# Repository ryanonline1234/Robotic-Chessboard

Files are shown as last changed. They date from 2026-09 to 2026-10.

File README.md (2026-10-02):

# Robotic Chessboard

A chessboard that moves its own pieces. An electromagnet on an XY gantry
slides under the board, grabs a piece through the wood, and drags it to its
square, weaving between the other pieces without touching them. It can play
the computer's moves, reset the board after a game, and set up any position.

The hard part of a board like this is the brain: deciding which piece goes
where, in what order, and along which route, so nothing collides. That part
is written and tested. This repo also holds the hardware design, CAD, wiring,
engineering calculations, machine-control software and parts list for the
first physical build.

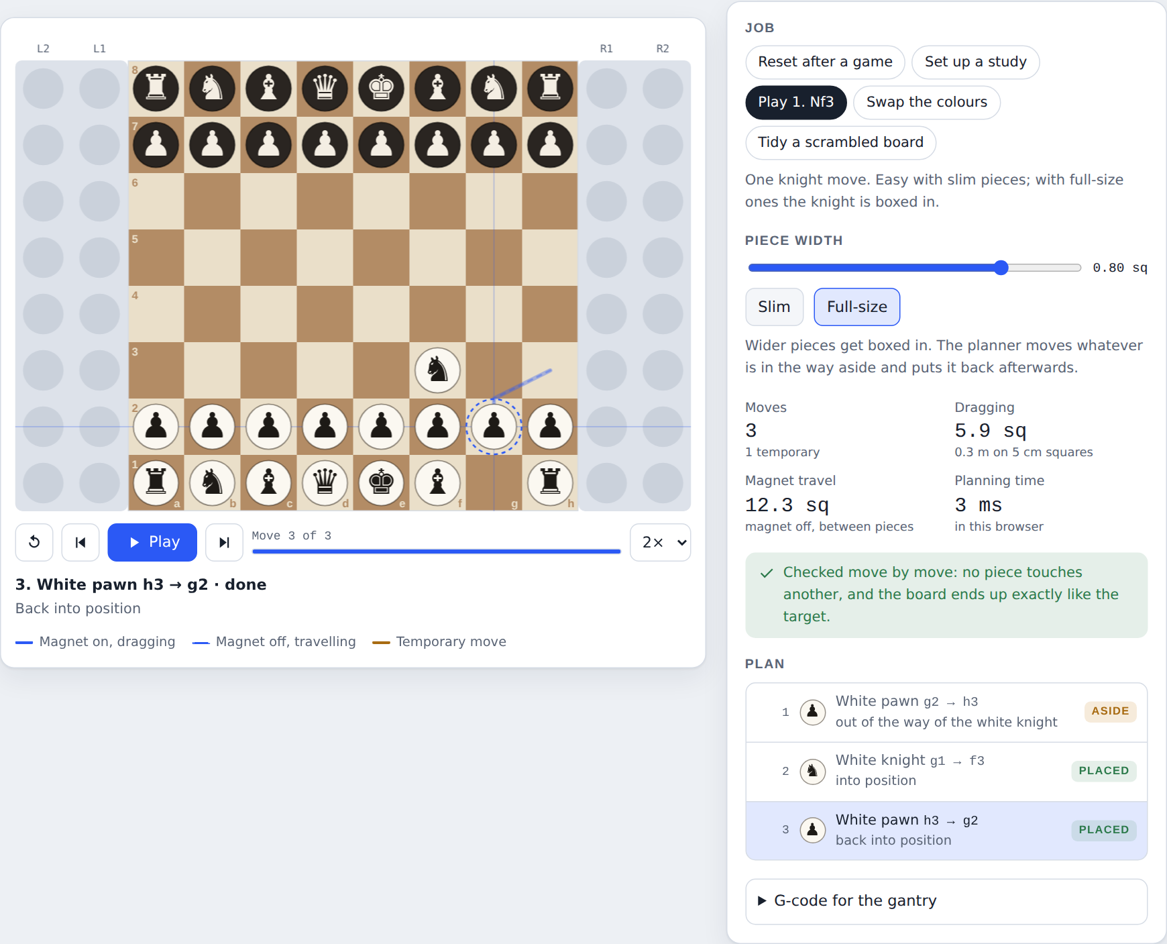
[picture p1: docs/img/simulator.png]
Simulator: a full-size pawn steps aside so the knight can get out, then goes back


## Status

| Part | State |
|---|---|
| Planning software: assignment, collision-free routing, blocker handling | ✅ Done |
| Independent plan checker | ✅ Done |
| G-code output for a GRBL gantry | ✅ Done |
| Animated simulator and command-line demo | ✅ Done |
| G-code sender and board calibration (`send.js`, `calibrate.js`) | ✅ Done, tested against a simulated GRBL |
| Automated tests | ✅ 70, all passing (`npm test`) |
| Hardware design, firmware settings | ✅ [docs/DESIGN.md](docs/DESIGN.md) |
| Engineering calculations | ✅ [docs/CALCULATIONS.md](docs/CALCULATIONS.md) |
| CAD: board sheet, layout drawing, pieces | ✅ [cad/](cad) |
| CAD: gantry, carriage and full assembly, printable STLs | ✅ [cad/README.md](cad/README.md) |
| Wiring schematic | ✅ [docs/img/wiring.svg](docs/img/wiring.svg) |
| Parts list, every price checked on 2026-10-01 | ✅ [docs/BOM.md](docs/BOM.md): $98.36 with tax, under the $100 budget, plus optional add-backs |
| Physical build | Next: [ROADMAP.md](ROADMAP.md) milestones 1–3 |

## What makes it different

- **It plans like a person tidying a board.** Identical pieces are
  interchangeable, so it matches each square with the nearest suitable piece,
  handles pieces that have to swap places, and routes every drag around the
  others with A* search. If a piece is boxed in, it moves the blocker aside and
  puts it back afterwards.
- **It checks its own work.** Every plan is replayed by a separate checker
  with brute-force geometry before a motor turns.
- **It was designed around a measurement, not a guess.** Simulating
  thousands of boards showed that pieces up to half a square wide never block
  each other. With 19 mm bases on 40 mm squares, every piece moves exactly
  once; full-size pieces need up to 2.5 times as many moves.
- **It explains itself.** Every move comes with a reason ("out of the way of
  the white knight") that can be shown on screen.

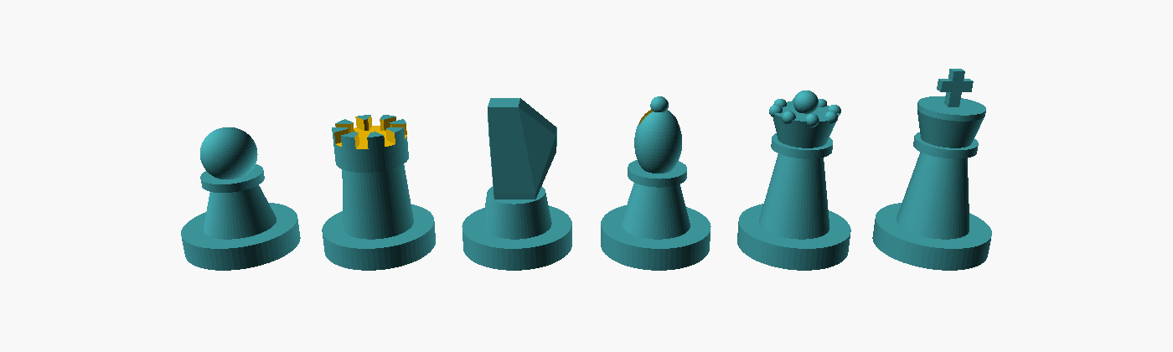
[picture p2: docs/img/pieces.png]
The six 3D-printable piece designs


## Try the software

Needs Node 20 or newer. The planner has no dependencies; `send.js` uses the
optional `serialport` package (`npm install`).

```bash
node demo.js                 # list the sample jobs
node demo.js reset           # put everything back after a game
node demo.js nf3 --big       # full-size pieces: it moves a blocker and puts it back
node demo.js reset --storage 1 --square 40 --size 0.475 --gcode reset.gcode   # G-code for the v1 board
node send.js reset.gcode --dry-run                                            # what would go to GRBL
npm test
```

On the machine, `calibrate.js` fits the G-code to the real board and
`send.js` streams it to GRBL; [docs/DESIGN.md](docs/DESIGN.md#software) has
the steps.

To watch it animated, run `npm run sim` and open
http://localhost:8000/simulator.html.

## How the planner thinks

1. **Assign.** Each target square is matched with a piece of the right type so
   the total distance is as small as possible (Hungarian algorithm, one run per
   piece type). Pieces left over go to storage.
2. **Order.** It runs whichever move has a free destination, nearest to the
   magnet first. When every destination is taken (pieces that must trade
   places), one of them steps onto a spare square first.
3. **Route.** Each drag is found with A* search on a half-square grid, and is
   only allowed if the dragged piece stays one full piece width from every
   other piece the whole way.
4. **Clear the way.** If a piece is boxed in, a second search finds the route
   that disturbs the fewest pieces. They step aside to spots they can get back
   from, then return. With full-size pieces it fills the board from the inside
   out and fills storage from the outer column in.
5. **Check.** `src/verify.js` replays the plan independently.

| Job | Slim pieces (0.45 of a square) | Full-size pieces (0.8) |
|---|---|---|
| Reset after a game | 22 moves | 26 moves (4 temporary) |
| Set up a study | 32 | 32 |
| Play 1. Nf3 | 1 | 3 (1 temporary) |
| Swap the colours | 48 (16 temporary) | 53 (20 temporary) |
| Chess960 setup, average of all 960 | 15.6 (3.6 temporary) | 38.3 (17.1 temporary) |

## Using it from code

```js
import { START_FEN, createBoard } from './src/board.js';
import { planArrangement } from './src/planner.js';
import { toGcode } from './src/gcode.js';

const board = createBoard({ storageColumns: 1 });
const now = { e4: 'P', d5: 'p', 'R1-1': 'Q' /* ...every piece, storage included */ };
const plan = planArrangement(board, now, START_FEN, { pieceDiameter: 0.475 });

for (const move of plan.moves) console.log(move.piece, move.from, move.to, move.why);
const gcode = toGcode(plan.moves, { squareMm: 40 });
```

Inputs can be a FEN string, a `Map` of cell to piece, or an object keyed by
cell name (`e4`, or `L1-3` / `R1-8` for storage slots). The target describes
the 64 play squares; anything not needed there ends up in storage. If a job is
impossible (a second queen that doesn't exist, or more captured pieces than
storage slots), you get `{ ok: false, error }` instead of a plan.

## Repo map

| Path | What it is |
|---|---|
| `src/` | Planner, routing, checker, G-code, sample jobs |
| `src/grbl.js`, `src/send-job.js` | GRBL 1.1 streaming protocol and the send job (errors, alarms, safe stop) |
| `src/calibration.js` | Fits the board to the machine from jogged positions |
| `tests/` | `node --test` suites: planner, G-code, calibration, GRBL streaming against a fake GRBL, CLIs, calculations |
| `demo.js` | Command-line demo; writes G-code |
| `send.js` | Streams a G-code file to GRBL over USB |
| `calibrate.js` | Writes `calibration.json` from the a1 and h8 positions |
| `simulator.html` | Animated top-down simulator |
| `scripts/calculations.js` | Computes every figure in `docs/CALCULATIONS.md` |
| `docs/DESIGN.md` | Hardware design, wiring, firmware settings, test plan |
| `docs/CALCULATIONS.md` | Engineering calculations and what Milestone 1 must measure |
| `docs/BOM.md` | Parts list and budget |
| `docs/img/` | Renders, wiring schematic (`wiring.svg`), screenshots |
| `cad/README.md` | Printed parts, hardware, assembly steps, clearances |
| `cad/params.scad` | Every shared dimension of the gantry |
| `cad/gantry-parts.scad` | The printed gantry parts |
| `cad/assembly.scad` | The whole machine, with fit and reach checks |
| `cad/export.sh` | Rebuilds the STLs and pictures and runs the checks |
| `cad/stl/` | Printable gantry parts |
| `cad/make-wiring.js` | Draws the wiring schematic |
| `cad/board-sheet.svg` | 1:1 printable playing surface (400 × 320 mm) |
| `cad/board-layout.svg` | Same, with dimensions and the magnet's travel area |
| `cad/make-board.js` | Regenerates both drawings for any square size |
| `cad/pieces.scad` | Parametric OpenSCAD pieces with a washer pocket |
| `ROADMAP.md` | Milestones from a magnet test to online play |
| `JOURNAL.md` | Build log |

## License

MIT, see [LICENSE](LICENSE).

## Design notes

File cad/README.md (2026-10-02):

# CAD

Everything needed to print and assemble the v1 gantry, plus the board sheet
and the chess pieces. The OpenSCAD files are parametric: every shared size
lives in `params.scad`.

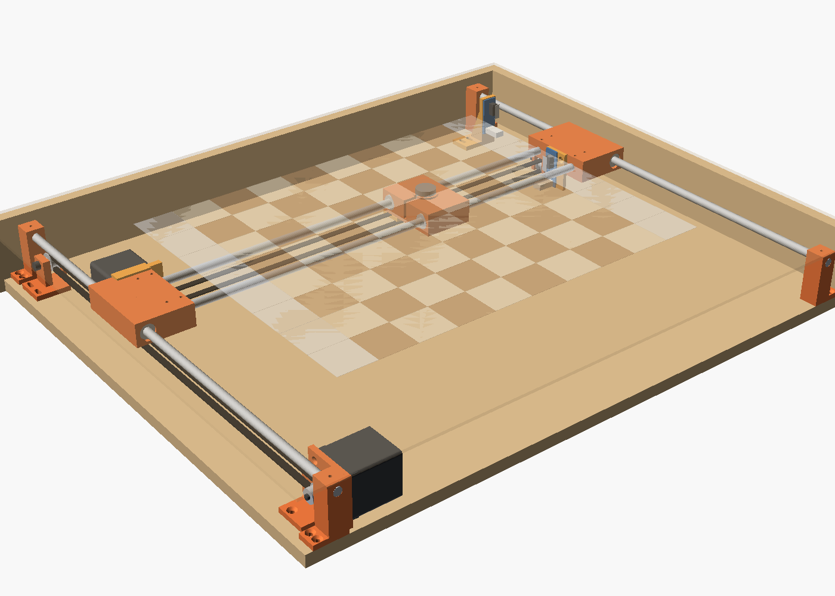
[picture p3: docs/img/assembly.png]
The assembled machine with the top see-through


## Files

| File | What it is |
|---|---|
| `params.scad` | Every shared dimension: grid, rods, bearings, motor, belt, idlers and their axles (`idler_bore`), magnet, clearances, heights, layout, travel limits |
| `gantry-parts.scad` | The ten printed gantry parts, one module each. `part="name"` exports one in its print orientation; `part="all"` lays them all out |
| `assembly.scad` | The whole machine with stand-ins for the bought parts, a section view, a top view, and `echo()` checks for reach, clearances and interference |
| `export.sh` | Writes every STL to `stl/`, renders the four pictures in `docs/img/` and prints the checks. Fails if a check fails. `IDLER_BORE=3` builds the 3 mm idler version ([below](#using-3-mm-idlers)) |
| `stl/` | The exported parts, ready to slice |
| `pieces.scad` | The six chess pieces with a pocket for the steel washer. Its header says to cover the washer with a felt pad; the funded build has no felt (an optional add-back), so the pieces slide on their bare PLA bases |
| `make-board.js` | Draws `board-sheet.svg` (print at 100% and glue on the top) and `board-layout.svg` (the same with dimensions) |
| `make-wiring.js` | Draws the wiring schematic (see its header) |

Regenerate everything with `bash cad/export.sh` (OpenSCAD 2021.01 or newer;
set `OPENSCAD=/path/to/openscad` if it is not on your PATH). On a Linux
machine with no screen, run it as `xvfb-run -a bash cad/export.sh`. It takes
about two and a half minutes, most of it the section picture.

## How it is laid out

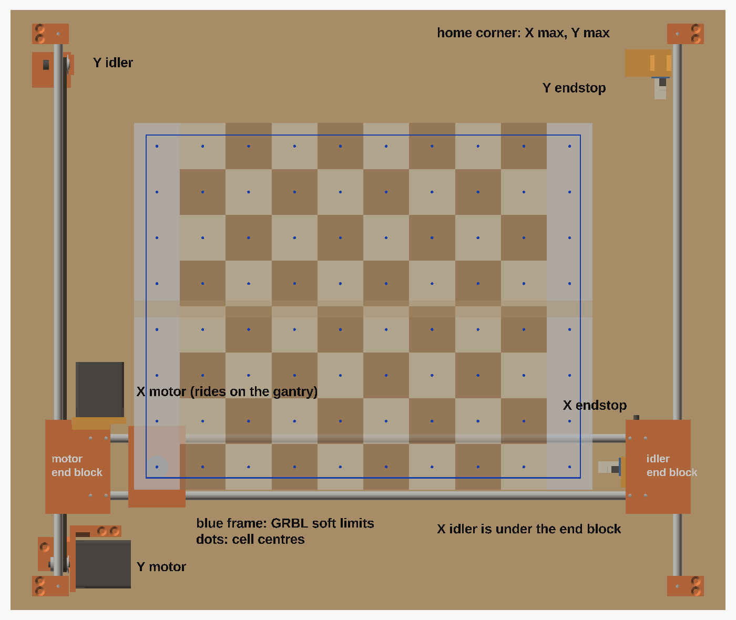
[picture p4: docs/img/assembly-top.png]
Top view, magnet under the front-left storage cell


Machine coordinates start at the front-left corner of the base's top
surface: X to the right (the board's 10 cells), Y away from you (the 8 ranks),
Z up.

- **Y axis.** Two 500 mm rods run front to back on the base at x = 30 and
  x = 570, each held by two printed holders. Each end block rides one rod on two
  LM8UU.
- **X axis.** The two X rods sit 50 mm apart in sockets in the two end
  blocks, at the same height as the Y rods (z = 42.5). Each rod end goes
  25.5 mm into its socket and is locked by two grub screws. The carriage rides
  the rods on four LM8UU.
- **Belts.** Both belts run in vertical loops right under the rods: the X belt
  under the rear X rod, the Y belt under the left end block's bearing housing,
  4.5 mm inboard of the left Y rod. Every pulley and
  idler axle is at z = 24.25, so the upper run of each belt lies flat against
  the underside of the part it pulls (z = 31) and is clamped there. The motors
  lie on their sides.
- **X motor** hangs behind the left ("motor") end block on the X motor mount;
  its pulley sits in a pocket under the end block. A lip along the top of the
  mount rests on the end block, so belt tension can't turn it. The **X idler**
  sits in a slot under the right ("idler") end block.
- **Y motor** is at the front left, **Y idler** at the back left on a mount
  that slides back up to 6 mm to tension the belt. The Y belt pulls the left
  end block, the side that carries the heavy X motor.
- **Switches** are at the back right (X max, Y max), because GRBL homes toward
  + unless `$23` says otherwise. The carriage presses the X switch, which sits
  on a bracket on the idler end block; the idler end block presses the Y
  switch, which sits on a post on the base. Both boards stand on end with the
  switch at the top and the connector at the bottom, below the part that
  presses the lever, so the plug can't stop the switch tripping however tall
  it is.
- **Top.** A frame of four 12 mm plywood walls screwed to the outside edges of
  the base carries the 3 mm top. Nothing touches the top from below except the
  magnet.

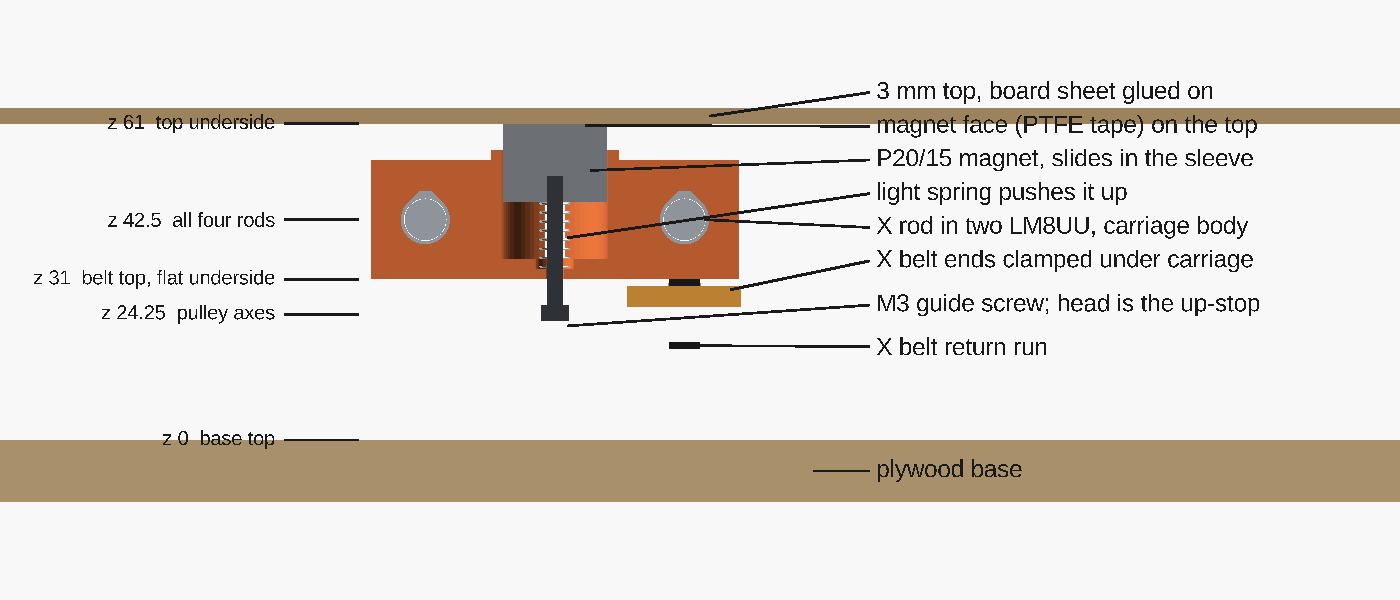
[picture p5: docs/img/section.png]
Section through the magnet: the stack-up


The magnet floats in a sleeve in the carriage. A light spring under it pushes
its face (with PTFE tape on it) up against the underside of the top. An M3
screw comes up through the carriage floor and threads into the magnet's back:
it keeps the magnet upright, and its head stops the magnet 5 mm above the top's
underside when the top is off.

## Printed parts

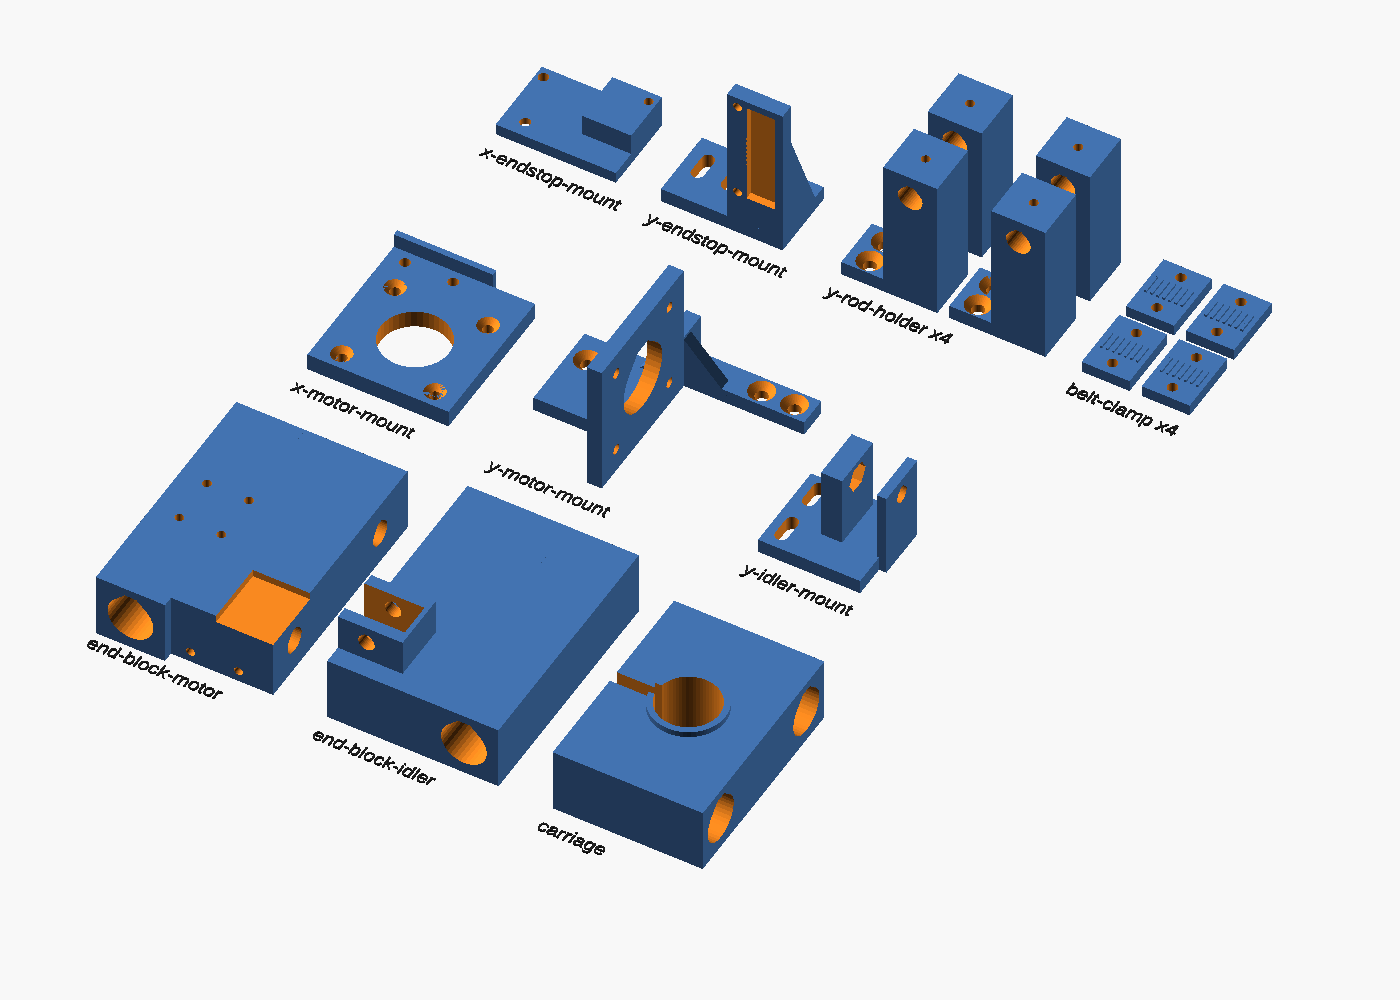
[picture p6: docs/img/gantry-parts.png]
All printed parts in their print orientation


PLA, 0.2 mm layers, 4 perimeters, 30% infill. No supports: horizontal holes
have a 45-degree roof and each part is turned so the only overhangs left are
bridges. The longest is the 9.5 mm roof of the solder-pin pocket in the X
endstop bracket; the rest are 6 mm or less (checked on the STLs). All parts
fit a 220 x 220 mm bed with lots of room.

| Part | Qty | How it sits on the bed | Size on the bed (mm) | Plastic, time (each) |
|---|---|---|---|---|
| `y-rod-holder` | 4 | Standing up, flange down | 32 x 18 x 51 | 12 g, 20 min |
| `end-block-motor` | 1 | Upside down (top face on the bed) | 57 x 82 x 23 | 55 g, 1.5 h |
| `end-block-idler` | 1 | Upside down, idler slot facing up | 57 x 82 x 36 | 58 g, 1.6 h |
| `x-motor-mount` | 1 | Flat, back face down, lip up | 47 x 52 x 11 | 11 g, 19 min |
| `carriage` | 1 | Upright, sleeve up | 50 x 71 x 25 | 41 g, 1.2 h |
| `y-motor-mount` | 1 | Upright, feet down | 73 x 58 x 47 | 16 g, 26 min |
| `y-idler-mount` | 1 | Upright, base down | 36 x 31 x 30 | 9 g, 15 min |
| `belt-clamp` | 4 | Flat, ridges up | 16 x 22 x 5 | 2 g, 3 min |
| `x-endstop-mount` | 1 | Flat, PCB side down | 40 x 27 x 12 | 6 g, 10 min |
| `y-endstop-mount` | 1 | Upright, foot down | 40 x 24 x 55 | 10 g, 17 min |
| **Total** | 16 | | | **about 260 g, 7.3 h** |

Plastic and time are rough estimates from the STL volumes, not from a slicer:
shell = surface area x 1.2 mm, plus 30% of the rest, at 1.24 g/cm³, laid down
at about 8 mm³/s. Your slicer will give better numbers. The chess pieces come
on top of this.

## Hardware

Bought parts from [docs/BOM.md](../docs/BOM.md) that the CAD uses: four 8 x 500
mm rods (uncut), eight of the ten LM8UU (four in the end blocks, four in the
carriage), two NEMA 17 motors, the belt kit's two 20T pulleys and its two 20T
toothed idlers (5 mm bore, on M5 axles), the P20/15 magnet, two mechanical
endstop modules and the PTFE tape for the magnet face. Belt: about 1.0 m for X
and 0.95 m for Y, out of the 5 m roll. Separate 3 mm-bore idlers are an
optional add-back; see [Using 3 mm idlers](#using-3-mm-idlers).

The idlers are drawn 18 mm across the flanges, 8.5 mm wide, 6.5 mm between
the flanges and 12.2 mm across the teeth, from one seller's drawing of a
5 mm-bore 20T idler. Motedis lists a 20T 5 mm-bore idler as 9 mm long, so
the slots take idlers up to 9 mm wide (`idler_w_max`). The nut pocket takes
the thickest nut ISO 4032 allows (4.7 mm for M5). Measure your idlers before
printing the idler end block and the Y idler mount. If one is wider than
9 mm, set `idler_w` and `idler_w_max` (and `idler_gap`) in `params.scad` to
what you measure and run the checks: `bash cad/export.sh`, or
`openscad -o checks.echo cad/assembly.scad` and look for FAIL in
`checks.echo`. If the idler axles check then fails, it names what no longer
fits; change the screw lengths (`x_axle_len`, `y_axle_len`) to suit, and buy
the screws its `SIZE idler axles` line prints.

The X motor must be no longer than 51 mm (the CAD draws a 48 mm body). A
longer one, such as a 60 mm high-torque NEMA 17, hits the back wall before
the Y switch stops the gantry.

The endstop parts are drawn for a 40 x 16 mm board with the switch at one end,
the 3-pin connector at the other, and two holes 35 mm apart, 2.5 mm in from
one long edge. One shop lists the v1.2 board as 36.5 x 16 x 10 mm overall. If
your board's holes are elsewhere, drill new 2.9 mm pilot holes in the bracket
and the post; keep the switch at the top.

Not in the BOM, needed for the build:

| Item | Qty | Where |
|---|---|---|
| M3 x 6 grub screws (set screws) | 12 | Lock the rods: 4 in the holders, 8 in the end blocks (two per X rod end; headless, so nothing sticks up toward the top) |
| M3 x 10 socket screws | 8 | Belt clamps: 4 under the carriage, 4 under the motor end block. Not longer: the pilot holes are 5 mm deep |
| M3 x 10 countersunk (flat head) | 9 | Both motors to their mounts, flush; 1 for the X endstop bracket |
| M3 x 16 socket screws | 2 | X motor mount to the motor end block |
| M3 x 12 socket screws | 2 | X endstop PCB to its bracket |
| M3 x 6 socket screws | 2 | Y endstop PCB to its post |
| M3 x 25 socket screw | 1 | Magnet guide screw |
| M5 x 30 socket screw | 1 | X idler axle: in from the front of the foot under the idler end block, nut on the back face. Its end stands about 4 mm out behind the end block, under it |
| M5 x 20 socket screw | 1 | Y idler axle: in from the outboard side of the Y idler mount, nut in the pocket in the thick cheek. Not longer: a longer screw sticks out into the X motor's path |
| M5 nuts (8 mm across flats, up to 4.7 mm thick: DIN 934 or ISO 4032), M5 washers (10 mm across, 1 mm thick) | 2, 4 | Idler axles (a washer each side of each idler) |
| Wood screws, 3.5-4 mm, about 16 mm long | 19 | 8 for the holders, 3 Y motor mount, 2 Y idler mount and 2 Y endstop post (pan head + washer, in slots), 4 for the top's corners; more for the walls |
| Compression spring | 1 | About 20 mm long, 5-7 mm across, fits over an M3 screw (inside 3.5 mm or more), light: 0.1-0.3 N/mm |
| 12 mm plywood or MDF strips | 2 + 2 | Walls: 624 and 500 mm long, 61 mm plus your base's thickness tall (73 mm for a base of exactly 12 mm) |
| 3 mm hardboard, smooth on both sides (S2S), or 3 mm MDF | 1 | Top, 624 x 524 mm |

The M3 screws in the printed parts cut their own thread in 2.9 mm pilot holes.
The idler axles go through 5.5 mm holes and take nuts. With 3 mm idlers, use
an M3 x 25 and an M3 x 18 socket screw, 2 M3 nuts and 4 M3 washers instead
of the M5 parts (so 2 M3 x 25 in all, with the guide screw). The M3 x 18 goes
in the Y idler mount; not longer, for the same reason as the M5 x 20.

## Assembly

1. **Check the fits.** A rod should slide through the 8.2 mm holes. Press the
   LM8UU into their bores with a vise, two per bore, one from each end until
   they stop against the shoulder in the middle. The magnet should slide
   freely in the sleeve; sand the sleeve if it doesn't. Cut a thread in every
   grub-screw hole by running an M3 socket screw (or an M3 tap) in and out:
   a grub screw on a 1.5 mm hex key can't cut its own thread in PLA.
2. **Carriage.** Put the spring in the pocket on the floor. Push the M3 x 25
   guide screw up through the floor and the spring and screw it into the back
   of the magnet until it bottoms out, then half a turn back. Lead the magnet's
   wires out through the slot. Put two layers of PTFE tape on the magnet face.
   The belt clamp screws come later; their holes pass about 1 mm from the
   bearing bores, so press the bearings in first and don't overtighten them.
3. **Motors.** Fit each pulley before the motor goes on its mount (the pulley
   passes through the 22.6 mm hole):
   - X motor: hub toward the motor, the pulley's end 7 mm from the motor face.
   - Y motor: hub away from the motor, the pulley's end 6 mm from the face.
   Bolt each motor to its mount with four countersunk M3 x 10. Turn the X
   motor so its connector points up or toward the carriage: it runs 3.1 mm
   above the base, and toward the left its plug would hit the Y idler mount.
4. **Gantry.** Slide the carriage onto both X rods. Push the rod ends into the
   two end blocks as far as they go (25.5 mm) and lock each with its two grub
   screws, which end up 1.5 mm below the top of the block. Hang the X motor
   mount on the back of the motor end block with its lip on top of the block,
   and fix it with two M3 x 16 from behind, above the motor. Put the X idler
   with a washer each side in the slot under the idler end block and push the
   M5 x 30 (M3 x 25 for 3 mm idlers) through from the front; the nut goes on
   the back face. Tighten the nut only until the cheeks touch the washers;
   the idler must still spin freely. If it drags, back the nut off, or use
   washers that touch only the bearing's inner ring. Do this before step 8:
   the X endstop bracket sits in front of the screw head.
5. **Y rods.** Stand the gantry on the base. Slide each Y rod in from outside
   through a holder, through the end block's bearings and into the far holder,
   flush with both outer faces, and lock it with the grub screws. Holders go at
   the corners of the base with their flanges outboard (turn the part 180
   degrees for the right side). Screw them down while the gantry slides freely
   end to end; the rods must be 540 mm apart at both ends.
6. **Y drive.** Screw the Y motor mount down at the front left (plate face at
   x = 40, front edge at y = 4); all three of its screws are clear of the Y
   rod. Fit the Y idler in its mount first: drop the nut into the hexagonal
   pocket on the inside of the thick (outboard) cheek, stand a washer, the
   idler and a washer between the cheeks, and screw the M5 x 20 (M3 x 18 for
   3 mm idlers) in from outside through the cheek, the nut, the washers and
   the idler. It ends inside the thin cheek, so nothing sticks out on the
   side the X motor passes. Tighten it snugly: the head and the nut clamp the
   thick cheek. Put the Y idler mount at the back left as far forward as it
   goes, with its axle at x = 34.5, y = 464 and each wood screw at the back end
   of its slot, so the mount can slide back. Drive its two wood screws with a
   screwdriver, or with a bit long enough that its holder stays more than
   25 mm above the mount's base (level with the top of the cheeks): the axle
   head is 1 mm from the bit's path, and a bit holder is wider than the bit.
   Clamp one end of the Y belt under the motor end block, take it forward
   round the Y pulley, back along the bottom, round the idler and forward to
   the second clamp. Pull the belt tight
   through that clamp with pliers and tighten it. Then slide the idler mount
   back (up to 6 mm) to finish tensioning and tighten its screws. Push the
   gantry all the way back by hand: the X motor passes 1.4 mm from the idler
   mount's inner cheek, so check it clears.
7. **X drive.** Same idea: one end under the carriage's left clamp, left round
   the X pulley, along the bottom to the X idler, back to the right clamp.
   Pull the end tight through the right clamp with pliers and tighten it.
   There is no screw tensioner on X: to re-tension later, loosen the right
   clamp from below with a short hex key, pull, and tighten again.
8. **Switches.** Both boards go switch up, connector down.
   - X: screw the bracket to the inner face of the idler end block with the
     countersunk M3 x 10, its block tucked under the end block. Fit the PCB
     with two M3 x 12: the top one goes on through the bracket into the end
     block, the bottom one into the bracket's block.
   - Y: fix the PCB to the post with two M3 x 6. Screw the post down at the
     back right (PCB at x = 547 to 563) and slide it so the switch clicks when
     the X motor is about 5.5 mm from the back wall.
   - Lead each switch cable straight down from its plug to the base, away from
     the carriage, the X belt and the X idler.
9. **Frame and top.** Measure the base's thickness and cut the walls so their
   tops stand 61 mm above the base's top face. Screw them to the outside edges
   of the base. Lay the top on, smooth side down where the magnet slides (with
   one-side-smooth hardboard the sheet will show the texture of the other
   side), and screw or pin it to the walls at the four corners, so it always
   goes back in the same place. Glue the board sheet with its front-left corner
   108 mm from the top's left edge and 105 mm from its front edge, within
   ±5 mm. That centres it in the area GRBL's soft limits allow; the
   calibration in DESIGN.md finds the exact offset.

## Key clearances

| What | Value |
|---|---|
| Rod holes (holders, end blocks) | 8.2 mm, locked with M3 grub screws; X rods 25.5 mm deep in each end block, two grub screws each |
| LM8UU bores | 15.2 mm press fit, 9.5 mm shoulder between the two bearings |
| M3 clearance / self-tapping pilot | 3.4 mm / 2.9 mm |
| Idler axles | 5.5 mm holes for M5 (3.4 mm for M3); slot 11.5 mm for an idler up to 9 mm wide (8.5 mm drawn) and two 1 mm washers (10.5 mm with M3 washers); nut pocket for a nut up to 4.7 mm thick. X: the M5 x 30 ends 5.8 mm past a 4.7 mm nut and 4.3 mm behind the end block's back face, its head 1.3 mm from the X endstop bracket. Y: the M5 x 20 ends 1.4 mm into the 3.3 mm inboard cheek, 1.9 mm short of the face the X motor passes; its head is 1 mm from a 7.3 mm screwdriver bit on the wood screws (so drive them with a screwdriver or a long bit, step 6). At least 1.9 mm of plastic round every axle hole and the nut pocket |
| Belt clamp pilots | 5 mm deep (an M3 x 10 goes in 4.6 mm); about 1 mm of plastic to the bearing bores in the carriage and to the shoulder bore in the motor end block |
| NEMA 17 | 31 mm M3 square, 22.6 mm hole for the 22 mm boss |
| Belts | Pulley and idler axles all at z = 24.25; upper runs at z = 30.4-31.0 on the flat undersides; return runs at z = 17.5-18.9, 3.7 mm below the clamp screw heads |
| Magnet in the sleeve | 20.6 mm bore for the 20 mm magnet |
| Spring | 13 mm long at work, 10 mm if the top sags 3 mm, 18 mm at the up-stop |
| Top | Underside at z = 61. Highest moving parts (sleeve rim, X motor mount lip) at z = 56: 5 mm clear, 2 mm with 3 mm of sag |
| Magnet reach | With `$130=380` and `$131=300` the soft limits allow x 105.9-485.9 and y 103-403. The cell centres are at x 115.9-475.9 and y 113-393: 10 mm to spare on every side (11.5 mm or more to the hard stops) |
| Travel for GRBL | Up to `$130=384` and `$131=309` fit before the far end of travel; DESIGN.md's 380 and 300 stop 4.4 mm (X) and 9 mm (Y) short of it |
| Ends of travel | Parts stop 1 mm apart (end block / Y motor mount, carriage / motor end block); on the home side the switches trip 1.5 mm before the switch body is reached, and the next part is 5.5 mm (Y) or 8 mm (X) away |
| Endstop plugs | Below the face that presses the lever, so any plug height clears; the checks assume a connector and plug up to 18 mm tall |
| Y idler mount | Slides back up to 6 mm; then 1 mm from the back-left holder |
| X motor | 3.1 mm above the base; 1.4 mm from the Y idler mount's inner cheek; at the Y switch's hard stop its back is 4 mm from the back wall (48 mm body) |
| Footprint and height | 624 x 524 mm; 76 mm to the playing surface (with a 12 mm base), 107.5 mm to the top of a king |

## Checks

`assembly.scad` prints these every time it runs (and `export.sh` stops if any
says FAIL):

- the magnet reaches every cell centre with at least 5 mm to spare inside
  GRBL's soft limits (`$130=380`, `$131=300`);
- those soft limits stop short of the hard stops at the far end of travel;
- nothing but the magnet comes within 1 mm of a top that sags 3 mm;
- the spring is never slack or crushed, and the magnet stays in its sleeve;
- the moving parts stay inside the base, so the walls are outside their path;
- each pulley's teeth line up with its belt, and the belts' return runs pass
  under the clamp screws. That the axles all sit at one height and the upper
  runs lie on the flat undersides holds by construction, so it isn't tested;
- at each switch's trip point, measured on the parts' bounding boxes: the
  switch body is still 1.5 mm away, and every other part (the endstop
  connectors and plugs included) is further away than that;
- a bounding-box test finds no overlap between moving and fixed parts at the
  four corners of travel;
- fixed parts that sit close to each other (motor mount and holders, the idler
  mount slid fully back, the Y endstop post) stay at least 1 mm apart;
- the idler axles (M5 or M3, from `idler_bore`), with each nut as thick as
  ISO 4032 allows and each idler as wide as the slots are drawn for, so
  thinner nuts and narrower idlers only leave more room: each hole suits its
  screw, the slots take an idler and two washers, the X axle reaches at least
  1 mm past its nut and its head clears the X endstop, the Y axle reaches
  1 mm or more into the inboard cheek but not out of its face (the X motor
  passes there), the Y axle's head leaves room for a screwdriver on the wood
  screws, and at least 1.5 mm of plastic is left round the holes and the nut
  pocket. The screw heads, the nuts and the X axle's end are also in the
  interference tests. A wrong screw length or nut size in `params.scad` makes
  it say FAIL, for example `-D x_axle_len=20` or `-D axle_nut_h=6`.

The exact interference test renders only the overlaps, at the four corners:

```bash
openscad -D 'check="collide"' -o /tmp/collide.stl cad/assembly.scad
```

OpenSCAD should answer "Current top level object is empty". To see that the
test can fail, push the gantry 6 mm past its front stop with
`-D check_push=6`: it then reports a solid. Each run takes about three
minutes.

Cables are not modelled, so none of these checks cover them.

## Using 3 mm idlers

The funded build uses the belt kit's two 5 mm-bore idlers on M5 axles. Separate
20T idlers with a 3 mm bore, on M3 axles, are an optional add-back. They have
the same outside size, so only two parts change: `end-block-idler` and
`y-idler-mount`. From the repo's top folder, export those two for M3 axles
and run the checks for that build:

```bash
openscad -D idler_bore=3 -D 'part="end-block-idler"' -o end-block-idler-m3.stl cad/gantry-parts.scad
openscad -D idler_bore=3 -D 'part="y-idler-mount"' -o y-idler-mount-m3.stl cad/gantry-parts.scad
openscad -D idler_bore=3 -o checks-m3.echo cad/assembly.scad
```

The two STLs come out in their print orientation, like the ones in `stl/`.
Every CHECK line in `checks-m3.echo` should end in OK, and its
`SIZE idler axles` line lists the M3 screws. The hardware for this option is
under [Hardware](#hardware).

`IDLER_BORE=3 bash cad/export.sh` does the whole export for the 3 mm build
instead: it passes `-D idler_bore=3` to every OpenSCAD run and stops if a
check fails. It overwrites all of `cad/stl/` and the pictures in `docs/img/`,
which in the repo are the 5 mm build; `git checkout cad/stl docs/img` puts
them back. Setting `idler_bore = 3` in `params.scad` switches every command
to the 3 mm build.

## Notes for the firmware and software

- Stock GRBL 1.1 homes Z first and stops with `ALARM:9` on a board with no Z
  switch. Flash it with `HOMING_CYCLE_0` set to X and Y together, as
  [CALCULATIONS.md section 12](../docs/CALCULATIONS.md) describes.
- There are no switches at X min and Y min. If a motor runs the wrong way,
  `$H` drives the carriage or the gantry into the hard stop at the far end and
  keeps going for up to 1.5 x `$130`. Before the first `$H`, jog in small steps
  (`$J=G91 X5 F500`, then `$J=G91 Y5 F500`) and check that +X moves the
  carriage right, toward the idler end block, and +Y moves the gantry back.
  If not, invert that axis with `$3`.
- With the switches at X max / Y max, GRBL's default `$23=0` is right. After
  homing, machine zero is where each switch trips and GRBL counts positions
  downward from there (`limits.c` and `system.c` in GRBL 1.1), so machine
  coordinates on this board run from -`$130` to 0 and the `offsetX` /
  `offsetY` found by jogging to a1 and h8 will be negative too (or set a work
  offset).
- GRBL has one limit input per axis. On the CNC Shield V3 the X- and X+ header
  pins are wired in parallel to that one input (according to builders' forum
  reports, not the maker's documentation), so the switch can plug into X- even
  though it sits at X max.

## Not checked yet

- The spring is not in the BOM, and its rate is a guess. Too stiff and the
  magnet drags on the top; too weak and it may not follow the top's sag.
- The magnet's thread depth, and where its wires leave it, were not measured.
  The slot in the sleeve leaves room either way.
- The endstop board: hole positions follow one datasheet, and the switch
  heights and the connector-and-plug size (18 mm tall) are estimates. A switch
  that trips at a different height only moves machine zero by the difference,
  which the 10 mm margins and the calibration absorb; the Y post can also
  slide to put it back.
- Pulley hub and tooth lengths are typical values, not measured.
- The idlers' size is one seller's drawing, and the belt kit's idlers were
  not seen; measure them. The slots take idlers up to 9 mm wide; see
  [Hardware](#hardware) for a wider one. Whether a 10 mm M5 washer touches
  only the idler's inner bearing ring, as it should, was not checked.
- How much the 600 x 500 mm span of 3 mm hardboard sags is an assumption (3 mm
  allowed). So is the advice about smooth sides: it comes from general
  knowledge of hardboard, not from a sheet measured here.
- The base must be flat to about 1 mm (check with a straightedge; MDF is
  safer than plywood), and nothing may lie on it in the strip the X motor
  sweeps (x 40-90, from y 130 to the back): the motor runs 3.1 mm above it.
- The gantry parts take about 260 g of PLA on top of the pieces, more than the
  BOM's 250 g for everything.
- The electronics are not modelled. Free space under the top: a strip along
  the front (x 95-520, y 0-52) and along the back (x 95-515, y 446-500), both
  61 mm high. Cable routing for the magnet, X motor and switches is not
  modelled either; leave slack loops so nothing reaches the belts.
- The X belt has no screw tensioner; it is tensioned by hand at the carriage
  clamp. GT2 belt stretch over time was not looked up.
- Racking: the Y belt pulls only the left end block (the one with the X
  motor). The right end block is dragged through the X rods, which sit
  25.5 mm deep in both blocks with two grub screws each, and each block runs
  on two LM8UU 79 mm apart end to end. If the rod joints stay rigid, the two
  rods resist racking at about 10.7 N/mm (beam theory, 2 x 12EI/L³ over the
  449 mm between the end blocks; not measured); if a grub screw loosens as the
  PLA creeps, the joint can turn and the right end lags. Whether the gantry stays square is something
  Milestone 2's pen test has to show (draw the right-hand storage column).
- Heat: the magnet sits in a PLA sleeve. PLA softens around 55-60 °C. The
  magnet is only on while dragging, but if it gets too warm to touch during a
  long job, print the carriage in PETG.

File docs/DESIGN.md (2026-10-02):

# Design: compact robotic chessboard (v1)

A chessboard that moves its own pieces. An electromagnet on an XY gantry
slides under the board top, switches on under a piece, drags it along a
route that avoids every other piece, and switches off. The route planning is
done by the software in this repo and sent to the gantry as G-code.

Simulator showing the planner moving a pawn out of the way for a knight

## Specs

| | |
|---|---|
| Square size | 40 mm |
| Grid | 10 × 8 cells: the 8 × 8 board plus one storage column on each side (16 slots for captured pieces) |
| Board surface | 400 × 320 mm, printed sheet on 3 mm hardboard ([cad/board-sheet.svg](../cad/board-sheet.svg)) |
| Magnet travel | 360 × 280 mm between the outermost cell centers ([cad/board-layout.svg](../cad/board-layout.svg)) |
| Machine size | 624 × 524 mm, 76 mm tall to the playing surface ([cad/assembly.scad](../cad/assembly.scad)) |
| Pieces | 3D-printed, 19 mm bases (0.475 of a square), 21–32 mm tall, M8 washer in each base ([cad/pieces.scad](../cad/pieces.scad)); felt pads optional |
| Magnet | 12 V holding electromagnet, 20 mm, switched by a MOSFET from GRBL's `M8`/`M9` |
| Motion | Two NEMA 17 steppers (45 N·cm on Y, a 40 N·cm 17HS4401 on X), GT2 belts, 8 mm rods with LM8UU bearings |
| Controller | Arduino Uno + CNC Shield V3 running GRBL 1.1 |
| Brain | This repo's planner, on a laptop or Raspberry Pi, over USB |
| Power | 12 V 3 A adapter (5 A optional), 5 A fuse |
| Parts | [BOM.md](BOM.md): $98.36 with tax for the funded build, plus optional add-backs |
| Numbers behind the design | [CALCULATIONS.md](CALCULATIONS.md) |

Why 19 mm bases: the planner models each piece as a disc. Pieces up to half a
square wide always fit along the lines between other pieces, so every piece
moves exactly once. Wider pieces get boxed in and need extra moves (the README
has the numbers).

The six piece designs

## Mechanical

The gantry with the board top see-through

The whole machine is modelled in OpenSCAD in [cad/](../cad): every shared
size in [params.scad](../cad/params.scad), the printed parts in
[gantry-parts.scad](../cad/gantry-parts.scad), and the full assembly with its
fit checks in [assembly.scad](../cad/assembly.scad).
[cad/README.md](../cad/README.md) has the parts table, the extra screws,
assembly steps and the key clearances. `bash cad/export.sh` rebuilds the STLs
and pictures and stops if any check fails.

Side section through the magnet carriage

- **Frame:** two Y rods on the base along the left and right edges, held by
  four printed holders. The X gantry is two end blocks joined by the two X
  rods; each end block rides its Y rod on two LM8UU bearings. The magnet
  carriage rides the X rods on four more.
- **Drive:** one stepper per axis with a GT2 belt loop. The Y motor (the
  stronger, 45 N·cm one) sits at the front left and pulls the left end block.
  The X motor rides on that end block, so it must be no longer than 51 mm. The
  X idler sits inside the other end block. The idlers are the belt kit's
  20-tooth idlers with a 5 mm bore on M5 axles; the CAD switches to 3 mm-bore
  idlers on M3 axles with one setting (`IDLER_BORE=3`,
  [cad/README.md](../cad/README.md)). If the gantry racks because only one
  side is driven, move the Y belt toward the middle of the gantry.
- **Constant gap:** the magnet slides in a sleeve in the carriage on an M3
  guide screw, and a light spring pushes it up against the underside of the
  top. Its face is covered in PTFE tape. Magnetic pull falls off quickly with
  distance, so this keeps the grip the same across the whole board, even
  where the top sags.
- **Board top:** a 3 mm sheet on walls around the edge of the base, 5 mm
  above the highest moving part. Nothing supports it from below inside the
  travel area.
- **Homing:** the two endstops sit at the back-right corner (X max, Y max).
  The carriage presses the X switch and the idler (right) end block presses
  the Y switch.
- **Printed parts:** 16 parts, about 260 g of PLA and 7 hours of printing, all
  support-free on a 220 × 220 mm bed: 4 Y rod holders, the motor and idler end
  blocks, the X motor mount, the magnet carriage, the Y motor and Y idler
  mounts, 4 belt clamps, and the X and Y endstop mounts. The STLs are in
  [cad/stl/](../cad/stl).

All printed gantry parts

## Electrical

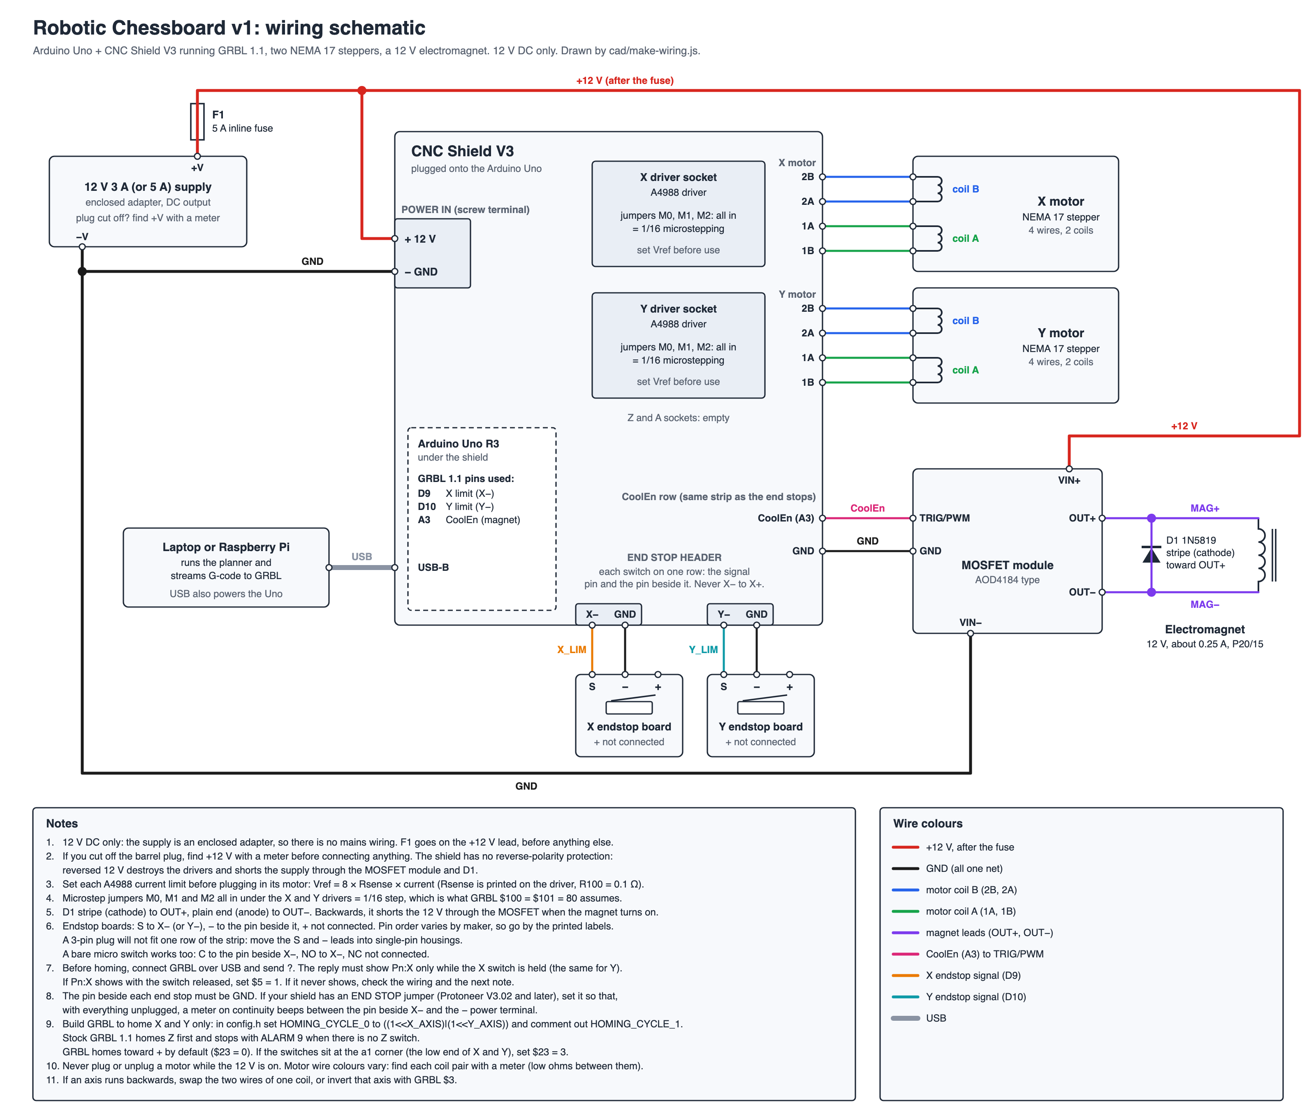
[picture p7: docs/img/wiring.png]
Wiring schematic


Click the picture for the full-size SVG. It is drawn by
[cad/make-wiring.js](../cad/make-wiring.js), and its notes cover current
limits, microstep jumpers, diode orientation and the endstop check.

| From | To | Notes |
|---|---|---|
| Supply +12 V | Fuse, then the shield's power terminal and the MOSFET module's VIN+ | 12 V only, no mains wiring. If you cut off the plug, find +12 V with a meter first: the shield has no reverse-polarity protection |
| Supply −V | Shield GND and the MOSFET module's VIN− | One shared ground |
| Shield X / Y driver sockets | X and Y steppers | Set each A4988's current limit (Vref) before plugging in its motor; all three microstep jumpers in for 1/16 |
| Shield `X-` and `Y-` endstop pins | Endstop boards | S to `X-` (`Y-`), − to the pin beside it, + not connected. Before homing, send `?` and check `Pn:X` shows only while the switch is held |
| Shield `CoolEn` (Arduino A3) and GND | MOSFET module TRIG/PWM and GND | GRBL `M8` turns the magnet on, `M9` off |
| MOSFET module OUT+ / OUT− | Electromagnet | 1N5819 across the magnet terminals, stripe (cathode) to OUT+ |
| Arduino USB | Laptop or Raspberry Pi | Powers the Arduino and carries the G-code |

Power: about 0.87 A from the 12 V 3 A adapter, estimated from the power the
motors, drivers and magnet actually use, so a 3.4× margin. The worst-case
bound, every coil at its full current at once, is 3.22 A, just over 3 A; the
5 A adapter is an optional add-back. Milestones 2 and 3 measure the real draw
([CALCULATIONS.md §11](CALCULATIONS.md#11-power-budget-and-magnet-heat)).

## Firmware settings (GRBL 1.1)

**Flash GRBL with a two-axis homing cycle.** Stock GRBL 1.1 homes Z first,
and this board has no Z switch, so `$H` fails with `ALARM:9`. Before
compiling and uploading GRBL, edit `grbl/config.h`:

```c
#define HOMING_CYCLE_0 ((1<<X_AXIS)|(1<<Y_AXIS))  // home X and Y together
// #define HOMING_CYCLE_1 ((1<<X_AXIS)|(1<<Y_AXIS))
```

Then set these, from [CALCULATIONS.md §12](CALCULATIONS.md#12-recommended-grbl-settings):

| Setting | Value | Meaning |
|---|---|---|
| `$5` | 0 | Limit pins read as triggered when pulled low: suits switches to GND (GRBL's default) |
| `$100`, `$101` | 80 | Steps per mm: GT2 belt, 20-tooth pulley, 1/16 microstepping |
| `$110`, `$111` | 6000 | Maximum speed, mm/min. Y is near the end of its motor's flat torque here, so test Y before raising `$111` |
| `$120`, `$121` | 400 | Acceleration, mm/s²: about 30× below where the king tips, about 3× torque margin |
| `$11` | 0.010 | Junction deviation (GRBL's default) |
| `$20` | 1 | Soft limits after homing |
| `$22` | 1 | Homing on |
| `$23` | 0 | Home toward +X and +Y: the switches are at X max and Y max (GRBL's default) |
| `$25` | 1500 | Homing seek speed, mm/min: homing takes up to 18.7 s, against about 49 s at the default 500 |
| `$130`, `$131` | 380, 300 | Travel limits, mm (the CAD has room for up to 384 and 309) |

Keep the defaults for `$24`, `$26` and `$27`: the slow second approach is what
makes the homed position repeat. After homing, machine coordinates run from
−`$130` to 0 and −`$131` to 0, so the board's offsets come out negative.
Before the first `$H`, jog in small steps and check that +X moves the carriage
toward the idler end block and +Y moves the gantry back; if not, invert that
axis with `$3` ([cad/README.md](../cad/README.md)).

## Software

1. The planner (`src/planner.js`) takes the current arrangement, storage
   included, and a target position, and returns the moves with routes and
   reasons.
2. `src/verify.js` replays the plan and rejects it if any piece would touch
   another.
3. `calibrate.js` fits the board to the machine. Jog the magnet to the
   centers of a1 and h8 (and h1 and a8 for a better fit), then run
   `node calibrate.js --a1 X,Y --h8 X,Y --storage 1 --square 40`. It works out
   the board's offset, the real square size on each axis and any small
   rotation, and writes `calibration.json`. It refuses measurements that look
   like a jog to the wrong square (`--force` overrides).
4. `src/gcode.js` turns the moves into G-code for this board:
   `toGcode(moves, { calibration })`, or `{ squareMm: 40, offsetX, offsetY }`
   without a calibration.
5. `send.js` streams the G-code to GRBL over USB. It waits for each `ok`, and
   leaves the magnet off whenever it stops: after an `error` (it sends `M9`),
   an `ALARM` (GRBL resets itself) or Ctrl-C (feed hold, then reset). It needs
   the optional `serialport` package (`npm install`).

For this board:

```bash
node demo.js reset --storage 1 --size 0.475 --calibration calibration.json --gcode reset.gcode
node send.js reset.gcode --port /dev/ttyUSB0 --home
```

`node send.js reset.gcode --dry-run` prints what would be sent without a
machine attached.

## How it will be tested

These are the "done when" checks from [ROADMAP.md](../ROADMAP.md):

1. **Magnet:** a king follows the magnet 20 cm through the board top ten times
   in a row and stays put when it's off. [CALCULATIONS.md](CALCULATIONS.md#what-milestone-1-should-measure)
   lists what to measure along the way.
2. **Gantry:** after homing, a pen on the carriage hits all 80 cell centers
   within ±1 mm, three runs in a row.
3. **Moves:** the 22-move reset job runs three times with every piece centered
   on its square.
4. **Game:** a full game against Stockfish, then a reset.

## Open questions

- **Grip.** Can the 20 mm magnet drag a king through 3 mm of hardboard plus
  paper? The two estimates in [CALCULATIONS.md](CALCULATIONS.md) straddle the
  pull needed, so this is the biggest risk, and Milestone 1 answers it before
  anything else is built.
- **Pieces the magnet passes.** Drags pass standing pieces 20 mm away with
  the magnet on. The magnet's sideways pull there has to fall to under a
  quarter of its peak, or it drags them along too. Milestone 1 measures it,
  and any fix for weak grip has to be checked against it.
- **Tipping.** On paper the king tips only above about 11500 mm/s² in the
  worst case (no felt, washer flush with the base), 29× the acceleration
  used; Milestone 3 confirms it.
- **Racking.** Is one Y motor enough, or does the gantry rack? Test it in
  Milestone 2.
- **Bought-part sizes.** The endstop board's hole positions, the washers'
  outer diameter and (if you add them) the felt pads' thickness aren't stated
  in their listings; measure them before printing the mounts and pieces.
- **Felt or no felt.** The funded build leaves the felt out. Milestone 1
  tests the pieces both ways; felt is an inexpensive add-back.

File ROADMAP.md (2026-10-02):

# Roadmap: from planner to a real magnet chessboard

The planner in this repo already works. It turns "here is the board now, here
is how it should look" into collision-free drags and G-code. This roadmap
covers the rest: building a board that moves real pieces and plays a game
with you.

It is split into milestones you can finish one at a time, each with a
**done when** test. The first ones are cheap experiments that catch the
problems most likely to sink the project before you have spent much money.
Time estimates assume part-time work (a few hours on a weekend) and leave out
shipping, which can take one to three weeks for parts ordered online.

## How the board works

```
          chess pieces (steel washer in each base, felt pad optional)
  ═══════════════════════════════════════════════════  3 mm board top
                    ┌───────────┐
                    │ electro-  │  rides on the XY carriage, pressed
                    │ magnet    │  lightly against the underside of the top
  ──────────────────┴───────────┴──────────────────  X beam
  Y rails on both sides, two stepper motors and belts

  laptop or Raspberry Pi ──USB──▶ Arduino Uno + CNC Shield (GRBL)
  runs this planner                moves the motors, switches the magnet
```

The planner decides the moves. GRBL firmware on an Arduino drives two stepper
motors to position the magnet, and switching the magnet on and off grabs and
releases pieces.

## Decisions to make first

| Decision | Recommendation | Why |
|---|---|---|
| Square size | 40 mm | Keeps the whole grid at 400 × 320 mm, so short rods and a $100 budget cover it. 50 mm squares are a later upgrade. |
| Storage | One column on each side, 16 slots (`createBoard({ storageColumns: 1 })`) | Enough for the captures in almost every game. The planner refuses a job that needs more room than exists. |
| Pieces | 3D-printed, 19 mm bases ([cad/pieces.scad](cad/pieces.scad)) | At up to half a square wide, pieces slide between the others, so each piece moves once (see the table in the README). |
| What the magnet grabs | An electromagnet on the carriage and a steel washer in each piece, with no magnets in the pieces | A piece with a magnet in it sticks to the electromagnet's iron core even when the power is off, and gets dragged around. |
| Gantry | A simple XY frame on 8 mm rods and LM8UU bearings, one motor per axis | Cheap and easy to build and debug. An aluminium extrusion frame is stiffer and a good later upgrade. |
| Controller | Arduino Uno + CNC Shield V3 running GRBL 1.1, A4988 drivers | Cheap, well documented, and runs the G-code this repo writes. TMC2209 drivers are quieter if the budget allows. |
| Knowing where pieces are | Version 1: no sensors. Version 2: sensors under the squares. | The software can track every move it makes itself. Sensors are a big job, so add them once everything else works. |

The full design is in [docs/DESIGN.md](docs/DESIGN.md) and the parts in
[docs/BOM.md](docs/BOM.md).

## Milestone 0: planner and simulator ✅

Done in this repo:

- [x] Assign pieces to target squares, order the moves, and route every drag around the other pieces
- [x] Move blockers aside and back when full-size pieces are boxed in
- [x] Independent checker that replays each plan
- [x] G-code output for a GRBL gantry
- [x] Animated simulator (`simulator.html`) and command-line demo (`demo.js`)

## Milestone 1: magnet test (1 weekend, about $30)

The riskiest question is whether a magnet under the board can drag a piece
smoothly. Answer it before building anything else.

- [ ] Buy a 12 V electromagnet (20–25 mm across, rated for 2–3 kg of holding force), a logic-level MOSFET module, a flyback diode (1N5819 or 1N4007), a 12 V power supply, M8 steel washers (16 mm across), and a 3 mm sample of your board material (acrylic, MDF or plywood). A few felt pads are optional, to compare.
- [ ] Wire the magnet through the MOSFET, with the diode across the magnet's terminals and its stripe toward +12 V. Without the diode, switching the coil off can destroy the MOSFET.
- [ ] 3D-print three test pieces: a pawn, a knight and a king (the tallest), from [cad/pieces.scad](cad/pieces.scad). Glue a washer into each base and check with a straight edge that it sits flush with the base or just below it. Test them bare first (the funded build has no felt), then with a felt pad on the bottom if you have some.
- [ ] Hold the magnet under the board sample, by hand or on a block, and drag each piece around. Try gaps from 1 to 5 mm and different speeds.
- [ ] Measure what [docs/CALCULATIONS.md](docs/CALCULATIONS.md#what-milestone-1-should-measure) lists: the pieces' friction on the board sheet, the magnet's downward and sideways pull, whether a passing magnet drags a standing pawn, and how hot the magnet gets.

**Done when:** the king follows the magnet across 20 cm ten times in a row
without tipping or getting left behind, and stays put when the magnet is off.

**If it fails:** use a thinner board top, a bigger washer, a stronger magnet or
a heavier, wider base; drag more slowly; keep the top smooth and the pieces on
felt.

## Milestone 2: the gantry moves accurately (2–3 weekends, about $70)

- [x] Design the rod holders, end blocks, magnet carriage and motor, idler and endstop mounts in CAD, and check that the assembly fits and reaches every cell ([cad/](cad))
- [ ] Print the 16 gantry parts ([cad/stl/](cad/stl), about 260 g of PLA)
- [ ] Build the frame: 8 mm rods on a plywood base with LM8UU bearings, following the assembly steps in [cad/README.md](cad/README.md). The carriage has to reach every cell center: a 360 × 280 mm range for 40 mm squares.
- [ ] Mount two NEMA 17 stepper motors with GT2 belts and 20-tooth pulleys, plus a limit switch on each axis for homing.
- [ ] Flash GRBL 1.1 onto the Arduino and set it up:
  - first edit `config.h` so homing runs X and Y only (`HOMING_CYCLE_0`); stock GRBL homes Z first and fails with `ALARM:9` on this board
  - steps per mm, `$100` and `$101`: 80 for GT2 belts on 20-tooth pulleys at 1/16 microstepping, or 40 at 1/8 (check your driver's jumpers)
  - maximum speed, `$110` and `$111`, and acceleration, `$120` and `$121`
  - homing, `$22=1`, `$23=0`, `$25=1500`
  - the full table is in [docs/DESIGN.md](docs/DESIGN.md#firmware-settings-grbl-11)
- [ ] Drive it by hand from a free G-code sender such as Universal Gcode Sender, CNCjs or LaserGRBL.
- [ ] Accuracy test: tape paper over the frame, clip a pen to the carriage, and visit all 80 cell centers.

**Done when:** after homing, the pen hits every square center within ±1 mm,
three runs in a row.

## Milestone 3: first automated moves (1–2 weekends)

- [ ] Mount the electromagnet on the carriage on a light spring, with PTFE tape on its face, so it presses gently against the underside of the board top.
- [ ] Connect the MOSFET input to the CNC Shield's coolant pin (`CoolEn`, Arduino pin A3). `M8` then turns the magnet on and `M9` turns it off, which is what `toGcode` writes.
- [ ] Fix the board top on a frame around the edges, and glue on the printed sheet from [cad/board-sheet.svg](cad/board-sheet.svg) (print at 100% scale).
- [ ] Calibrate: jog the magnet to the centers of a1 and h8 and run `node calibrate.js --a1 X,Y --h8 X,Y --storage 1 --square 40`, which writes `calibration.json`.
- [ ] Set up the pieces the way `node demo.js reset --storage 1` prints its starting board, write the G-code with `node demo.js reset --storage 1 --size 0.475 --calibration calibration.json --gcode reset.gcode`, and run it with `node send.js reset.gcode --port <port> --home`.
- [ ] Tune the drag speed (start at 1000 mm/min), the acceleration, and the pause after switching the magnet.

**Done when:** the 22-move reset job runs three times in a row with every
piece centered on its square at the end.

## Milestone 4: play a game against the computer (2–3 weekends)

No sensors yet. You enter every move on a screen, your own included, and the
robot moves all the pieces. The software always knows where everything is,
because it made every move itself.

- [x] Software: `send.js`, which streams G-code to GRBL over USB. It homes with `$H` first (`--home`), sends one line at a time and waits for `ok`, and stops on `error` or `ALARM` with the magnet off. Tested against a simulated GRBL; not yet run on hardware.
- [ ] Software: save the physical position of every piece, storage included, to a file after each finished move, so a crash or restart doesn't lose track.
- [ ] Software: a game loop using chess.js for the rules and Stockfish for the computer's moves. After each move, plan from the current arrangement to the new position. Captured pieces go to storage automatically.
- [ ] Software: turn `simulator.html` into a controller. Click a piece and a square to make a move, preview the plan, then send it.
- [ ] Keep two spare queens in storage for promotions. The planner refuses any target it doesn't have the pieces for.

**Done when:** you play a full game against Stockfish to checkmate, and then
one click resets the board.

## Milestone 5: detect moves made by hand (3–4 weekends)

- [ ] Put a sensor under each of the 64 squares: reed switches or Hall-effect sensors (for example the A3144), read through eight 74HC165 shift registers or four CD74HC4067 multiplexers by the Arduino, an ESP32 or a Raspberry Pi.
- [ ] These sensors need a small magnet in every piece, which brings back the sticking problem from the decisions table. Before committing, test a fix: put the electromagnet on a small servo lift so it drops away when it's off, use a servo-lifted permanent magnet instead, or change the planner so the magnet travels along the lines between squares when it's off.
- [ ] Software: read the occupancy grid over serial and work out your move with chess.js. A normal move empties one square and fills another, a capture empties two squares before one fills, and castling changes four squares.
- [ ] Software: after every robot move, compare the sensors with the expected position, and retry or warn when a piece didn't land.

**Done when:** you play a whole game by hand without touching the screen, and
the board notices when you knock a piece off its square.

## Milestone 6: online play and polish (ongoing)

- [ ] Play online through the Lichess Board API, which is made for physical boards: stream your game and send your moves with a personal API token.
- [ ] Make it quieter: TMC2209 drivers in StealthChop mode, rubber feet, gentler acceleration.
- [ ] Make it faster: aim for an average robot move under 5 seconds.
- [ ] Build an enclosure with a power switch, a fuse and tidy wiring.
- [ ] Run a reliability soak: random jobs from `src/scenarios.js` overnight, counting misplaced pieces.
- [ ] Planner: a look-ahead search to cut temporary moves when pieces are full size.

## Parts and budget

The funded v1 build comes to $98.36 with tax and shipping, every price
checked on 2026-10-01; the itemised list is in [docs/BOM.md](docs/BOM.md).
Four parts were cut or downgraded to fit the $100 tier (separate 3 mm idlers,
felt pads, a 5 A adapter and a second 45 N·cm motor). They are listed there
as add-backs to buy at build time, with spares for the riskiest parts; the
design works with or without them. Milestone 5 adds roughly $20–40 for sensors, shift
registers and wiring. Quieter TMC2209 drivers and an aluminium extrusion frame
are good upgrades once v1 works.

## Risks to watch

| Risk | Early warning | Fix |
|---|---|---|
| Magnet too weak through the board | Drags stutter in Milestone 1 | Thinner top, bigger washer, stronger magnet, slower drags |
| Pieces follow the magnet when it's off | Pieces creep during travel moves | No magnets in pieces, or lift the magnet away (Milestone 5) |
| The magnet drags pieces it passes | A standing piece next to a drag route shifts | Measure it in Milestone 1; route drags farther from standing pieces, or use a magnet whose pull falls off faster |
| Tall pieces tip over | The king wobbles when a drag starts | Lower acceleration, a heavier or wider base, felt pads |
| Board top sags | Drags work at the edges but not in the middle | The spring-loaded magnet follows the top; otherwise use a stiffer top |
| Squares drift out of line | Pieces land off-center on one side | Square up the frame, then redo homing and calibration |
| Too noisy | Reviews of commercial robotic boards complain about this | TMC2209 drivers, rubber mounts, slower moves |
| Magnet overheats | Too hot to touch after a long job | It's only on while dragging; use PWM to lower its power |

## Safety

- Use low voltage only: 12 or 24 V from an enclosed power supply. Don't wire mains power yourself.
- Put a fuse on the 12 V line and secure every wire so nothing can catch in the belts.
- Always fit the flyback diode across the electromagnet.

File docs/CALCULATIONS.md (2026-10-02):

# Engineering calculations (v1)

The numbers behind the v1 design in [DESIGN.md](DESIGN.md): resolution,
speed, motor torque, the pieces' mass and balance, whether the magnet can
drag them, frame sag, belt length, how long a reset takes, power and heat.

The figures are for the funded build in [BOM.md](BOM.md): no felt under the
pieces, a 12 V 3 A adapter, a generic 17HS4401 motor on X and a STEPPERONLINE
17HS15-1504S-X1 on Y. Where an optional add-back
([BOM.md: Add back when building](BOM.md#add-back-when-building)) changes a
figure, that case is worked too: felt pads in sections 4 to 7, the 5 A
adapter in section 11. The idlers (the belt kit's 5 mm-bore ones, or the
optional 3 mm-bore ones) are 20-tooth either way and change no figure here.

[`scripts/calculations.js`](../scripts/calculations.js) computes and prints
every figure in this document:

```bash
node scripts/calculations.js                          # uses the piece geometry recorded in the script
node scripts/calculations.js --export-stl /tmp/pieces # re-exports the pieces with OpenSCAD and re-measures them
node scripts/calculations.js --stl-dir /tmp/pieces    # re-measures STLs you already exported
```

`npm test` runs the script too ([tests/calculations.test.js](../tests/calculations.test.js))
and checks that the key figures quoted here still match what it prints. Some
of them come from other code: the reset job's time and magnet duty depend on
the planner and on the defaults in `src/gcode.js`. If a change moves one, the
test fails until this document is updated.

Every input is labelled:

- **design**: fixed by the v1 design ([DESIGN.md](DESIGN.md), [BOM.md](BOM.md), [cad/pieces.scad](../cad/pieces.scad), [src/gcode.js](../src/gcode.js))
- **source**: checked against a datasheet, a product listing or GRBL's source code (listed at the end)
- **assumption**: an estimate. The ones that change a conclusion are measured in Milestone 1 (see [What Milestone 1 should measure](#what-milestone-1-should-measure)).

## Results at a glance

| § | Check | Result | Verdict |
|---|---|---|---|
| 1 | Resolution | 80 steps/mm, 0.0125 mm per microstep | Far finer than the ±1 mm target |
| 2 | Top speed | `$110` = 6000 mm/min uses 27% of GRBL's step rate, and 24.5% (X) and 38.5% (Y) of each motor's rule-of-thumb roll-off speed. On Y's published curve the torque holds its peak up to 38.5% of that speed. Counting back-EMF (a rough check), Y's current stays controllable up to about 281 rpm, 1.9× the 150 rpm of 6000 | Comfortable on X. Y is at or a little past the end of its flat torque: fine at 6000, don't raise `$111` without testing |
| 3 | Motor torque | 3.48 N·cm needed on Y, 11.1 N·cm usable from its 45 N·cm motor; 3.25 N·cm needed on X, 9.9 N·cm usable from its 40 N·cm 17HS4401 | 3.2× margin on Y and 3.0× on X at 400 mm/s²; 2.8× and 2.9× at 1000 |
| 4 | Pieces | 3.39–3.73 g each, about half of it the steel washer; centre of gravity 3.6–5.6 mm above the board with no felt (1 mm higher with the optional felt) | Low and stable |
| 6 | Tipping | The worst piece (king) tips at about 13600 mm/s² with no felt (11300 with the optional felt), with no help from the magnet | 34× (28× with felt) above `$120` = 400, not a risk |
| 5, 7 | Grip | A centred pull of about 0.161 N is needed. At the funded build's 3.4 mm gap (no felt) the two estimates are 0.0118 N and 0.200 N, and other points of the same curve give up to 0.268 N. With the optional felt (4.4 mm): 0.0054 N and 0.143 N, up to 0.203 N. None of these is a bound | **Not settled on paper: the biggest risk. Milestone 1 decides it** |
| 7 | Pieces the magnet passes | Drags pass standing pieces 19.9–20 mm away with the magnet on. At μ = 0.3 the sideways pull there must stay below 0.0100 N (what holds a pawn), while the dragged piece needs about 0.040 N | **Not checked on paper. Milestone 1 measures it**, and every fix for weak grip must be re-checked against it |
| 8 | Rod sag | 0.66 mm at the middle of the board, worst case | The magnet's spring takes it up |
| 9 | Belts | 2200 mm of the 5000 mm roll | Plenty |
| 10 | Reset job | 110.8 s (1.8 min); magnet on for 71% of it | The drag feed is the setting that matters |
| 11 | Power | Estimated 0.87 A from the funded build's 3 A adapter (an energy balance). The worst-case bound, 3.22 A, is 0.22 A over 3 A, but reaching it would take 35.6 W in the motors and drivers against 7.4 W estimated | Enough: 3.4× margin on the estimate. Milestones 2 and 3 measure the real draw; the 5 A adapter is an optional add-back |
| 11 | Magnet heat | +19 K after one reset or in a game; +113 K if resets run back to back for half an hour | Fine for play; watch it in long test runs |
| 12 | Homing | Stock GRBL 1.1 homes Z first and stops with an alarm on a board with no Z switch | **Flash GRBL with a two-axis homing cycle** (section 12); homing then takes up to 18.7 s |

## 1. Steps per mm

| Input | Value | Basis |
|---|---|---|
| Belt pitch | 2 mm | design (GT2) |
| Pulley | 20 teeth | design |
| Motor | 200 full steps per turn (1.8°) | source: both motor listings (X: 17HS4401, Y: 17HS15-1504S-X1) |
| Microstepping | 1/16 | design (A4988, all three jumpers fitted) |

The funded build has two different motors. Y moves the whole gantry,
including the X motor, so it gets the stronger one, a STEPPERONLINE
17HS15-1504S-X1 (45 N·cm, 1.5 A). X moves only the magnet carriage and gets a
generic 17HS4401 (40 N·cm, 1.5 A). A second 17HS15-1504S-X1 for X is an
optional add-back. Below, figures tagged "17HS4401 listing" are for the X
motor and come from one seller's listing, not the one the BOM buys from, so
check the listing of the one you buy. Figures tagged "17HS15-1504S-X1
listing" are for the Y motor, from StepperOnline's product page and its
Amazon listing, which agree.

One pulley turn moves the belt 20 teeth × 2 mm = 40 mm.

steps/mm = full steps per turn × microsteps ÷ (teeth × pitch) = 200 × 16 ÷ 40

| Microstepping | Steps/mm | mm per step |
|---|---|---|
| 1/16 | 80 | 0.0125 |
| 1/8 | 40 | 0.0250 |
| full step | 5 | 0.2000 |

**Conclusion:** `$100` = `$101` = 80 with the 1/16 jumpers fitted, or 40 at 1/8.
Step size does not limit accuracy: even a full step (0.2 mm) is five times
finer than the ±1 mm target in Milestone 2. Belt stretch, frame squareness
and calibration will.

## 2. Speed: step rate and `$110` / `$111`

| Input | Value | Basis |
|---|---|---|
| GRBL step-rate ceiling on an Uno | 30000 steps/s per axis | source: GRBL 1.1 README |
| Supply | 12 V | design |
| Motor inductance, X | 2.8 mH per phase | source (17HS4401 listing) |
| Motor inductance, Y | 4.4 mH ±20% per phase (measured at 1 kHz) | source (17HS15-1504S-X1 listing) |
| Motor current | 1.05 A (70% of 1.5 A) | design (DESIGN.md sets Vref to about 70%) |

GRBL keeps a 30000 steps/s limit in its config file but leaves it switched off,
so it will accept faster settings; it just can't produce clean steps beyond that.

max feed = 30000 ÷ steps/mm × 60 = **22500 mm/min at 1/16** (45000 mm/min at 1/8).

So the step rate is not what limits speed. At the chosen `$110` = `$111` = 6000 mm/min:

- 100.0 mm/s = 8000 steps/s, 27% of the ceiling
- 2.50 motor turns per second (150 rpm), 500 full steps/s
- a diagonal rapid (`G0`) runs at 8485 mm/min, because GRBL limits each axis separately

A rule of thumb for the speed where a stepper's torque falls off: the coil
current can still reach full value in one full step up to about V ÷ (2 L I)
full steps per second. At 12 V and 1.05 A:

| Axis | Motor | L | V ÷ (2 L I) | As a feed | 6000 mm/min is |
|---|---|---|---|---|---|
| X | 17HS4401 | 2.8 mH | 2041 full steps/s | 24490 mm/min | 24.5% of it |
| Y | 17HS15-1504S-X1 | 4.4 mH | 1299 full steps/s | 15584 mm/min | 38.5% of it |
| Y, at the listing's +20% | 17HS15-1504S-X1 | 5.28 mH | 1082 full steps/s | 12987 mm/min | 46.2% of it |

The Y motor has more holding torque than X's (45 N·cm against 40) but more
inductance, so its torque starts to fall at a lower speed. The one published
pull-out curve found is for this motor: StepperOnline's, measured at 24 V and
1.5 A with 2000 microsteps per turn and a driver it doesn't name. It reads
42–43 N·cm from 30 to 210 rpm, then 40 N·cm at 300 rpm, 25 at 600 and 10 at
1200. The rule of thumb at the curve's own settings,
24 ÷ (2 × 4.4 mH × 1.5 A), gives 545 rpm, where the curve reads 28 N·cm, 65%
of its peak. The peak holds up to 210 rpm, 38.5% of that speed, and 93% of
it is left at 300 rpm, 55%. So on this motor the rule of thumb marks the
speed where about a third of the torque is already gone, not where the fall
begins.

`$111` = 6000 runs the Y motor at 38.5% of its own rule-of-thumb speed, the
same fraction as the end of the flat part of the curve: it should still have
about its low-speed torque, with little room to go faster before the torque
falls. X, at 24.5%, has more room. This comparison is rough. It assumes the
curve's shape scales with V ÷ (L I), which is the rule of thumb's own
assumption. It takes the curve's 1.5 A as the peak current; the curve
doesn't say, and read as an rms value the flat part would reach a higher
fraction, so on that question this is the cautious reading. No curve was
found for the 17HS4401.

The rule of thumb also leaves out back-EMF, the voltage the turning motor
generates in its own coils. Back-EMF is set by speed, not current, so it
takes twice the share of 12 V that it takes of 24 V, and on that count
scaling the 24 V curve down to 12 V is optimistic. A rough check that
includes it treats each phase as a sine-driven motor. Its torque constant
k_t is one phase's torque per amp on section 3's convention, holding torque
÷ (√2 × 1.5 A): 0.19 N·m/A on X and 0.21 on Y, an estimate. Its back-EMF at a rotor
speed ω (rad/s) is k_t ω (in SI units the torque constant and the back-EMF
constant are the same number), so a coil needs √((R I + k_t ω)² + (50 ω L I)²)
volts, where 50
is the number of electrical cycles per turn (200 full steps ÷ 4): the
back-EMF is in phase with the current and the inductive drop is 90° ahead of
it. The A4988's two transistors and sense resistor take 1.05 A × (2 × 0.43 +
0.1 Ω) = 1.01 V, which leaves 11.0 V:

| Axis | Needs at 150 rpm (6000 mm/min) | Current controllable up to | Multiple of 150 rpm |
|---|---|---|---|
| X, 17HS4401 | 5.1 V | about 388 rpm | 2.6× |
| Y, 17HS15-1504S-X1 | 6.8 V | about 281 rpm | 1.9× |
| Y, at the listing's +20% inductance | 7.2 V | about 256 rpm | 1.7× |

The same check at the curve's own 24 V and 1.5 A gives about 535 rpm (with
no driver drops, since the curve doesn't name its driver; that raises the
figure and makes what follows a little cautious). The curve's peak holds to
39% of that. `$111` = 6000 is 53% of Y's 281 rpm, and if the curve's shape
scales with this limit instead of V ÷ (L I), the curve at 53% of 535 rpm
(286 rpm) reads 40.5 N·cm, 94% of its peak. So counting back-EMF, Y at 6000
is a little past the end of the flat part rather than at it: still fine, with
less room to go faster than the rule of thumb suggests.

The default drag feed in `src/gcode.js`, `F2000`, is 33.3 mm/s or 2667 steps/s.

**Conclusion:** keep `$110` = `$111` = 6000. Section 10 shows that 10000
would only save 5 s on a whole reset, because most travel moves are short
and spend their time speeding up and slowing down. Y is the axis to test
first if `$111` is ever raised: it is already at or a little past the end of
the flat part of its torque curve, and the back-EMF check puts the speed
where its current can no longer keep up at about 1.9 times 6000.

## 3. Moving masses and motor torque

| Input | Value | Basis |
|---|---|---|
| 8 × 500 mm steel rod | 197.3 g | calculated: 7.85 g/cm³ (assumption) × π/4 × 8² × 500 mm |
| LM8UU bearing | 15 g | assumption (listings say 15–16 g) |
| Bearings on the carriage | 4 | assumption (two per X rod) |
| Printed carriage | 40 g | assumption |
| Electromagnet | 25 g | assumption (Adafruit's 5 V P20/15 is listed at 22.7 g) |
| Spring, screws, belt clamps on the carriage | 15 g | assumption |
| X motor (17HS4401) | 350 g | assumption (40 mm NEMA 17 bodies are often listed near 280 g; this allows a heavier one) |
| Printed end blocks and mounts | 80 g | assumption |
| Pulley, idler, screws on the gantry | 20 g | assumption |
| Resistance per axis | 5 N | assumption: binding from imperfect rod alignment, belt bending, the magnet's PTFE face sliding on the top |
| Holding torque | X: 40 N·cm; Y: 45 N·cm | source (17HS4401 listing; 17HS15-1504S-X1 listing) |
| Current factor | 1.05 A ÷ (√2 × 1.5 A) = 0.49 | assumption: the holding torque is rated with both phases at 1.5 A (the usual convention; neither listing says) |
| Speed derating | 0.5 | assumption: half of that torque is left at speed with microstepping |
| Rotor inertia | 54 g·cm² | source on X (17HS4401 listing). Not found for Y, so assumed the same (see below the table) |

- **Carriage** (moves in X): 4 × 15 g bearings + 40 g printed + 25 g magnet + 15 g hardware = **140 g**
- **Gantry** (moves in Y): 2 rods 395 g + 4 bearings 60 g + X motor 350 g + printed 80 g + hardware 20 g + carriage 140 g = **1045 g**
- **Piece**: at most 4.82 g (section 4). The magnet drags it, not the belts; its share of the load is negligible.

Belt force F = m a + resistance. Motor torque T = F r + J a ÷ r, where r is
the pulley's pitch radius, 20 × 2 mm ÷ 2π = 6.37 mm, and J the rotor inertia.

**Usable torque.** The A4988's current limit (1.05 A) is the peak of the sine
wave it drives through each coil when microstepping. At every microstep the
torque is then about what one phase gives at 1.05 A. If the X motor's
40 N·cm holding torque is rated with both phases at the full 1.5 A, one phase
at 1.5 A gives 40 ÷ √2 N·cm, so at 1.05 A the motor gives
40 × 1.05 ÷ (√2 × 1.5) = 40 × 0.49. Half of that is left at speed: usable
torque = 40 × 0.49 × 0.5 = 9.9 N·cm on X, and 45 × 0.49 × 0.5 = 11.1 N·cm on Y.

The Y motor's published curve (section 2) reads 43 N·cm at low speed at
1.5 A, where this model gives 45 ÷ √2 = 32 N·cm at 1.5 A before the speed
derating. So the model looks cautious if the curve's 1.5 A is the peak
current. Read as rms (2.12 A peak), the model gives 45 N·cm there, close to
the curve's 43, and the two agree with no hidden margin. The curve doesn't
name its driver or say which it means, so it is not used in place of the
model.

| Axis | Acceleration mm/s² | m a (N) | Resistance (N) | Belt force (N) | Torque (N·cm) | Usable (N·cm) | Margin |
|---|---|---|---|---|---|---|---|
| X | 400 | 0.06 | 5.0 | 5.06 | 3.25 | 9.9 | 3.0× |
| Y | 400 | 0.42 | 5.0 | 5.42 | 3.48 | 11.1 | 3.2× |
| X | 1000 | 0.14 | 5.0 | 5.14 | 3.36 | 9.9 | 2.9× |
| Y | 1000 | 1.04 | 5.0 | 6.04 | 3.93 | 11.1 | 2.8× |

The rotor's own inertia adds only 0.034 N·cm at 400 mm/s². The Y motor's
rotor inertia was not found: neither its product page nor its Amazon listing
gives it, and StepperOnline's full datasheet, a download from the product
page, was not opened. The table uses the 17HS4401's 54 g·cm² for it. Even at
twice that, Y would need 3.52 N·cm instead of 3.48.

**Conclusion:** the motors have about three times the torque needed: 3.2× on
Y and 3.0× on X at 400 mm/s². Y carries the heavier load, and its stronger
motor gives it the larger margin. The assumed 5 N of friction and binding is
most of the load, and the moving mass hardly matters. If an axis stalls or
skips, look for binding (rods out of parallel, a tight bearing) before
blaming the motor.

## 4. Piece mass and centre of gravity

**Method.** Each piece in [cad/pieces.scad](../cad/pieces.scad) was exported
as an STL (`$fn` = 64, OpenSCAD 2021.01). The script reads the triangles and
sums signed tetrahedra to get each piece's volume and the centre of that
volume, and sums the triangle areas to get the surface area and its centre.
The measured values are recorded in the script; `--stl-dir` or
`--export-stl` measures them again.

| Input | Value | Basis |
|---|---|---|
| PLA density | 1.24 g/cm³ | assumption (typical figure) |
| Infill | 20% | assumption (pieces.scad suggests 15–20%) |
| Solid walls | 0.8 mm | assumption: 2 perimeters of 0.4 mm, 4 top and bottom layers of 0.2 mm |
| M8 washer | 16 mm × 8.4 mm × 1.6 mm, steel 7.85 g/cm³ | design; density assumption |
| Washer position | glued against the top of the 1.8 mm pocket, so its face is 0.2 mm up inside it | assumption: glue between the washer and the top of the pocket makes the 0.2 mm smaller |
| Felt pad (optional add-back; the funded build has none) | 1.0 mm thick | assumption |

- **Printed mass** = 1.24 g/cm³ × (walls + 20% of the inside), where walls = surface area × 0.8 mm (at most the whole volume). A solid print (100%) is the upper bound.
- **Washer**: π/4 × (16² − 8.4²) × 1.6 = 233.0 mm³ of steel = **1.83 g**, its face 0.2 mm up inside the pocket and its centre 1.0 mm above the bottom of the base.
- **Centre of gravity** (CG) = (m_body × z_body + m_washer × z_washer) ÷ (m_body + m_washer), measured from the bottom of the base. In the funded build the base stands on the board, so that is the height above the board; the optional felt adds 1.0 mm to every height. The body's CG combines the walls (at the centre of the surface area) and the infill (at the centre of the volume).

| Piece | Height (mm) | Volume (cm³) | Area (cm²) | Printed (g) | Solid (g) | With washer (g) | CG (mm) | CG if solid (mm) | CG off-axis (mm) |
|---|---|---|---|---|---|---|---|---|---|
| pawn | 21.5 | 1.82 | 14.0 | 1.56 | 2.25 | 3.39 | 3.6 | 4.7 | 0.00 |
| rook | 22.0 | 2.41 | 16.4 | 1.90 | 2.99 | 3.73 | 4.9 | 6.2 | 0.00 |
| knight | 26.0 | 2.10 | 15.2 | 1.73 | 2.60 | 3.56 | 4.6 | 5.9 | 0.15 |
| bishop | 27.0 | 1.88 | 15.3 | 1.68 | 2.33 | 3.51 | 4.4 | 5.0 | 0.01 |
| queen | 28.0 | 2.30 | 16.5 | 1.88 | 2.85 | 3.71 | 5.4 | 6.6 | 0.00 |
| king | 31.5 | 2.34 | 16.6 | 1.90 | 2.90 | 3.73 | 5.6 | 6.8 | 0.00 |

"With washer" uses the 20% print; "CG off-axis" uses the solid print. The CG
columns are for the funded build; add 1.0 mm with the optional felt.

**Conclusion:** every piece weighs 3.39–3.73 g, and the 1.83 g washer is about
half of it, so the CG sits low: 5.6 mm above the board for the 31.5 mm king
(6.8 mm if printed solid; 6.6 and 7.8 mm with the optional felt), a quarter
of its height or less. The knight's head moves its CG only 0.15 mm off the
axis. The 34-piece set (32 plus two spare queens) needs about 58 g of PLA at
20% infill, before skirts and purges: the "about 60 g" the BOM allows for
the pieces, out of about 320 g of PLA on hand. The felt pad's own mass is
ignored.

## 5. Magnet pull through the board (estimate)

Every grip and tipping figure depends on how hard the magnet pulls the washer
through the board top. No force-versus-gap curve was found for the P20/15,
so this is the weakest estimate in the document.

**The gap** between the magnet face and the washer:

| Layer | Funded build (mm) | With the optional felt (mm) | Basis |
|---|---|---|---|
| PTFE tape on the magnet | 0.1 | 0.1 | assumption |
| Board top | 3.0 | 3.0 | design |
| Printed paper sheet and glue | 0.1 | 0.1 | assumption |
| Felt pad | none | 1.0 | design (the funded build has no felt); thickness an assumption |
| Washer recess in the pocket | 0.2 | 0.2 | assumption: the washer glued against the top of the 1.8 mm pocket (1.6 mm washer); glue there makes it smaller |
| **Total** | **3.4** | **4.4** | |

**The reference curve.** The closest published curve found is for the Eclipse
Magnetics M52180/12VDC, a 12 V holding magnet of similar size and power to
the P20/15, rated for 100% duty:

| | Eclipse M52180/12VDC | P20/15 (the BOM magnet) |
|---|---|---|
| Size | 20 mm across, 18 mm long | 20 mm across, 15 mm long |
| Mass | 36 g | 22.7 g (Adafruit's 5 V version) |
| Power | 2.5 W (12 V, 210 mA) | 3 W (12 V, 0.25 A) |
| Rated pull in contact | 53 N | 2.5–3 kg (24.5–29 N) in listings, about half the Eclipse's |

Its datasheet gives 53 N in contact, 22 N at 0.09 mm, 9 N at 0.18 mm, 5 N at
0.27 mm, 3 N at 0.36 mm, 2 N at 0.59 mm and 1 N at 1.00 mm (±10%), measured
on its M52171/25ARM armature plate, 25 mm across and 3 mm thick. The table
gives whole newtons only, so the last two points, 2 N and 1 N, fix the slope
only roughly. The pull has already dropped to 2% of its contact rating at
1 mm, and the table stops there.

Two ways to carry it on to 3.4 and 4.4 mm:

- **High estimate**: continue the slope between the last two points: F = 1 N × (1 mm ÷ gap)^1.31.
- **Low estimate**: scale down to the P20/15's lower rating (24.5 N, from listings that say 2.5 kg; some say 3 kg) and assume the pull falls with the cube of the gap beyond 1 mm: F = 1 N × 24.5/53 × (1 mm ÷ gap)³. (Assumption: once the gap is larger than the spacing between the magnet's poles, more of the flux goes straight from pole to pole without crossing the steel, so the pull falls faster than near contact.)

| Gap | High estimate (N) | Low estimate (N) | Heaviest piece's weight (N) |
|---|---|---|---|
| 3.4 mm (funded build, no felt) | 0.200 | 0.0118 | 0.047 |
| 4.4 mm (with the optional felt) | 0.143 | 0.0054 | 0.047 |
| 2.4 mm (no felt, 2 mm top) | 0.317 | 0.0334 | 0.047 |

The high estimate depends on which table points set the slope. The same
power law through the 1.00 mm point, starting from each earlier point:

| From | Exponent | Pull at 3.4 mm (N) | Pull at 4.4 mm (N) |
|---|---|---|---|
| 0.09 mm (22 N) | 1.28 | 0.208 | 0.149 |
| 0.18 mm (9 N) | 1.28 | 0.208 | 0.150 |
| 0.27 mm (5 N) | 1.23 | 0.222 | 0.162 |
| 0.36 mm (3 N) | 1.08 | 0.268 | 0.203 |
| 0.59 mm (2 N), the high estimate | 1.31 | 0.200 | 0.143 |

Neither estimate allows for the washer being smaller than the test plate, or
for the 8.4 mm hole in its middle. Adafruit gives the P20/15 a "center
diameter" of 8 mm, which on a pot-shaped holding magnet like this is the
centre pole, so the hole sits right over it. Both make the real pull lower;
by how much was not worked out.

**Conclusion:** through the funded build's 3.4 mm the two extrapolations
give 0.0118 N and 0.200 N, 0.25 and 4.23 times the weight of the heaviest
piece, and other points of the same table give 0.200 to 0.268 N. With the
optional felt (4.4 mm) they give 0.0054 N and 0.143 N, 0.11 and 3.02 times
that weight, and 0.143 to 0.203 N from other points. None of these is a
bound: the washer's shape can make the real pull lower than all of them, and
the table's coarse whole-newton points leave the high end uncertain. Leaving
out the 1 mm felt pad, as the funded build does, multiplies the pull by 1.40
on the high estimate and 2.17 on the low one. A 2 mm top would multiply the
funded build's pull by another 1.58 (high) or 2.84 (low).

## 6. Tipping

When the magnet speeds a piece up or slows it down, the piece's inertia acts
at its CG (height h) while the magnet drives it low down, at the washer
(height z_w). The piece would tip about the edge it stands on (radius r): the
edge of its printed base in the funded build, or of the felt pad with the
optional felt. Taking moments about that edge at the moment the far side
lifts, for the braking case (the worse one, because friction then adds to the
tipping moment):

m a (h − z_w) = (m g + F_v) (r − μ z_w)

**a_tip = (g + F_v ÷ m) × (r − μ z_w) ÷ (h − z_w)**

where F_v is the magnet's downward pull and μ the friction coefficient of
the base (or the felt) on the sheet. Speeding up gives r + μ z_w instead,
which is more stable. Ignoring the magnet's pull and putting the drive at the
board surface gives the simple bound **a_tip = g r ÷ h**, which is lower than
the full formula whenever r > μ h. That holds for every piece here, in both
cases, so the simple bound is the safe figure.

| Input | Funded build (no felt) | With the optional felt | Basis |
|---|---|---|---|
| r, less the CG's off-axis offset | 9.5 mm, the edge of the 19 mm base | 9.0 mm, an 18 mm felt pad cut a little inside the base | design ([cad/pieces.scad](../cad/pieces.scad)); the felt's size is an assumption |
| z_w | 1.0 mm | 2.0 mm | washer centre (section 4), plus the felt |
| μ | 0.3 | 0.3 | assumption (section 7) |
| F_v, 0.5 × the centred pull at that gap | 0.0059 N (low estimate) or 0.100 N (high) | 0.0027 N (low) or 0.071 N (high) | assumption (section 7) |
| h, m | solid prints from section 4 | the same, h 1 mm higher | the heavier, higher-CG case |

- A: g r ÷ h, no magnet pull, drive at the board surface
- B: g (r − μ z_w) ÷ (h − z_w), drive at the washer while braking, no magnet pull
- C: the full formula with the magnet's pull, low and high estimates

Funded build, no felt:

| Piece | CG (mm) | Mass (g) | A (mm/s²) | B (mm/s²) | C low (mm/s²) | C high (mm/s²) | A ÷ `$120` |
|---|---|---|---|---|---|---|---|
| pawn | 4.7 | 4.08 | 19900 | 24500 | 28100 | 85700 | 50× |
| rook | 6.2 | 4.82 | 15100 | 17500 | 19700 | 54500 | 38× |
| knight | 5.9 | 4.43 | 15600 | 18200 | 20700 | 60200 | 39× |
| bishop | 5.0 | 4.16 | 18500 | 22400 | 25600 | 77500 | 46× |
| queen | 6.6 | 4.68 | 14100 | 16100 | 18100 | 51200 | 35× |
| king | 6.8 | 4.73 | 13600 | 15500 | 17400 | 48900 | 34× |

With the optional felt:

| Piece | CG (mm) | Mass (g) | A (mm/s²) | B (mm/s²) | C low (mm/s²) | C high (mm/s²) | A ÷ `$120` |
|---|---|---|---|---|---|---|---|
| pawn | 5.7 | 4.08 | 15500 | 22400 | 23900 | 62200 | 39× |
| rook | 7.2 | 4.82 | 12300 | 16000 | 16900 | 40100 | 31× |
| knight | 6.9 | 4.43 | 12600 | 16600 | 17600 | 43900 | 32× |
| bishop | 6.0 | 4.16 | 14600 | 20500 | 21800 | 56300 | 37× |
| queen | 7.6 | 4.68 | 11600 | 14700 | 15600 | 37500 | 29× |
| king | 7.8 | 4.73 | 11300 | 14100 | 15000 | 35900 | 28× |

(Rounded to the nearest 100 mm/s².)

**With no felt the washer is exposed.** The washer pocket is open at the
bottom of the base, 16.4 mm across in the 19 mm base
([cad/pieces.scad](../cad/pieces.scad)), so a piece with no felt stands on a
1.3 mm ring of PLA, with the washer's face 0.2 mm above the board (section
4). If the washer sits flush with that ring or stands proud of it, as glue
between the washer and the top of its pocket or a washer as thick as the
1.8 mm pocket would make it, the piece stands on the steel instead. Its
friction on the sheet changes (no figure for steel on paper was looked for),
it tips about the washer's edge (r = 8.0 mm), and the washer may mark the
printed sheet. Tipping is still no risk: A for the king becomes 11500 mm/s²,
29× `$120`. Milestone 1 checks where the washers sit
([What Milestone 1 should measure](#what-milestone-1-should-measure)).

**Conclusion:** even with no help from the magnet, the king only tips above
about 13600 mm/s² in the funded build, 34 times the 400 mm/s² that `$120` /
`$121` allow. With the optional felt it is 11300 mm/s², 28 times: the pad is
narrower than the base and lifts the CG by 1 mm. Either way the washer keeps
the CG low enough that GRBL's acceleration cannot tip a piece. If a king
wobbles in testing, look elsewhere first: the base (or the felt) catching on
a seam or the edge of the sheet, a piece being dragged into another one, or a
piece that falls behind the magnet and is yanked when it catches up.

## 7. Grip: does the piece follow the magnet?

While the magnet drags a piece, the piece trails behind it until the sideways
pull matches the resistance. The base (or the felt, if added) resists with μ
times the total downward force, which is the piece's weight **plus the
magnet's own downward pull**, so a stronger magnet adds friction as well as
grip:

- needed sideways force = μ (m g + F_v) + m a
- available sideways force = s F_v

where s is the ratio of sideways to downward pull at the trailing offset
where the sideways pull is largest. The piece keeps up if

**F_v (s − μ) ≥ μ m g + m a**

If s is no bigger than μ, no magnet is strong enough.

| Input | Value | Basis |
|---|---|---|
| Piece | rook, solid print: 4.82 g, weight 0.0473 N | section 4 (the heaviest) |
| m a | 0.0019 N at 400 mm/s² | |
| μ, the piece on the paper sheet | 0.3 (0.2–0.4 tried) | assumption: no published figure found for bare printed PLA on paper (the funded build) or for felt on paper (the optional add-back), so the same value and range stand for both |
| s | 0.5 (0.4–0.7 tried) | assumption: no source found |
| F_v at that offset | 0.5 × the centred pull | assumption |

The m a term is small next to friction (μ m g = 0.0142 N), so a lower
acceleration barely helps grip.

**The funded build has no felt.** That is lever 2 at the end of this
section, already taken, and it changes three things:

- **The gap** is 3.4 mm instead of 4.4, so the magnet pulls 1.40 (high estimate) to 2.17 (low) times as hard, on the dragged piece and on the pieces it passes alike (section 5).
- **The friction coefficient** is that of the printed base on the sheet, not felt. Neither was found, so both keep μ = 0.3 with 0.2–0.4 tried. Milestone 1 measures bare PLA first, then felt.
- **Standing pieces** feel the stronger pull too. What holds one in place is μ m g with the base's μ (plus friction from the magnet's downward pull on it, which only helps and is ignored below), while the sideways pull on it grows with the magnet's strength. "Pieces the magnet passes" below works out what that asks of the magnet.

The next two tables don't depend on the felt; the comparison after them
covers both gaps.

Centred pull needed (N), for each μ and s:

| μ | s = 0.4 | s = 0.5 | s = 0.7 |
|---|---|---|---|
| 0.2 | 0.114 | 0.076 | 0.046 |
| 0.3 | 0.322 | 0.161 | 0.081 |
| 0.4 | never | 0.417 | 0.139 |

The largest gap that still gives that pull, for s = 0.5, on the two curves
from section 5:

| μ | Pull needed (N) | High-estimate gap (mm) | Low-estimate gap (mm) |
|---|---|---|---|
| 0.2 | 0.076 | 7.1 | 1.8 |
| 0.3 | 0.161 | 4.0 | 1.4 |
| 0.4 | 0.417 | 1.9 | 1.0 |

With μ = 0.3 and s = 0.5, the 0.161 N needed compares with:

| Gap | Pull | ÷ pull needed | Sideways force needed (N) | Available (N) | Ratio |
|---|---|---|---|---|---|
| 3.4 mm, funded build | High estimate, 0.200 N | 1.24 | 0.0462 | 0.0501 | 1.08 |
| 3.4 mm, funded build | Top of the range from other table points, 0.268 N | 1.66 | 0.0564 | 0.0671 | 1.19 |
| 3.4 mm, funded build | Low estimate, 0.0118 N | 0.07 | 0.0179 | 0.0029 | 0.16 |
| 4.4 mm, with felt | High estimate, 0.143 N | 0.89 | 0.0375 | 0.0357 | 0.95 |
| 4.4 mm, with felt | Top of the range from other table points, 0.203 N | 1.26 | 0.0466 | 0.0508 | 1.09 |
| 4.4 mm, with felt | Low estimate, 0.0054 N | 0.03 | 0.0169 | 0.0014 | 0.08 |

Adding the felt back costs 1 mm of gap, so it only helps grip if the felt
slides enough more easily than bare PLA to make up for the weaker pull. With
bare PLA at μ = 0.3, felt breaks even at μ = 0.26 on the high estimate's
slope and 0.20 on the low one's; a felt with a higher μ than that makes grip
worse.

**Pieces the magnet passes.** A switched-on magnet pulls on every washer near
it, not only the one it is dragging. [src/motion.js](../src/motion.js) keeps
at least one piece diameter, 19 mm (0.475 × 40 mm), between a dragged
piece's centre and every other piece's centre. In the 22-move reset job,
drags pass a standing piece within 20 mm 22 times; the closest is 19.9 mm.
A washer 20 mm off the magnet's axis has its near edge 12 mm from the axis,
just outside the magnet's 10 mm radius. A standing piece slides towards the
magnet once the sideways pull on it is more than μ (m g + F_v there). The
lightest piece is a pawn at 20% infill (3.39 g). The table compares the
sideways pull the dragged piece needs (s × F_v at the centred pull needed,
s = 0.5) with what holds a standing pawn, ignoring the magnet's downward
pull on the pawn, which only helps it stay put:

| μ | Centred pull needed (N) | Peak sideways pull needed on the dragged piece (N) | What holds a standing pawn, μ m g (N) | Ratio of the two |
|---|---|---|---|---|
| 0.2 | 0.076 | 0.0190 | 0.0067 | 2.9× |
| 0.3 | 0.161 | 0.0403 | 0.0100 | 4.0× |
| 0.4 | 0.417 | 0.1043 | 0.0133 | 7.8× |

So the design needs a pull that is strong right over the piece and weak
20 mm out. At μ = 0.3, with a magnet just strong enough to drag the rook,
the sideways pull 20 mm from the axis must be under a quarter of its peak
over the dragged piece. A stronger magnet needs the pull to fall off even
faster, because what holds a standing pawn stays the same. That is the
funded build's case if the high end of section 5 holds: at the 3.4 mm gap,
the peak sideways pull (s × 0.5 × the centred pull) is 5.0 times what holds
a standing pawn at the high estimate (0.200 N) and 6.7 times at the top of
the range (0.268 N), so the pull 20 mm out must fall below a fifth, or a
6.7th, of its peak. With the felt the same figures are 3.6 and 5.1 times.
Leaving the felt out strengthens the pull on the pieces the magnet passes
along with the one it drags. No force-versus-offset data were found to check
this. Milestone 1 measures it (step 4).

**Conclusion:** on paper the grip is unsettled. In the funded build (3.4 mm,
no felt) the high estimate of the pull is a little more than what is needed:
1.24 times it from the last two table points, up to 1.66 times from other
points of the same table, which gives 1.08 to 1.19 times the sideways force
needed. The low estimate gives less than a fifth of that force. With the
optional felt (4.4 mm) the high estimate is about equal to what is needed
(0.89 to 1.26 times) and the low one gives less than a tenth. This is the
"riskiest question" the roadmap puts first, and these numbers cannot settle
it: the answer swings across the whole range with μ, s and the real pull,
none of which could be checked. Milestone 1 measures them. If they land at
the weak end, these are the levers (the first two are sized in the tables
above; the last two were not quantified):

1. Less friction under the piece, which raises s − μ: going from μ = 0.3 to 0.2 halves the pull needed (0.161 N to 0.076 N). A smoother sheet, or a pad that slides better than bare PLA; felt (the optional add-back) helps only if its μ is low enough to pay for the 1 mm it adds to the gap (see above).
2. A smaller gap. The funded build already leaves out the 1 mm felt, which multiplies the pull by 1.40 to 2.17 over the felt version (section 5). A 2 mm top would multiply it by another 1.58 to 2.84.
3. A plain steel disc without a hole instead of the M8 washer.
4. A stronger magnet.

Each lever also changes how hard the magnet pulls on the pieces it passes,
so re-check every one against that limit. Levers 2, 3 and 4 strengthen the
pull 20 mm out as well as over the dragged piece. Lever 1 lowers what holds a
standing pawn (0.0100 N to 0.0067 N), but it lowers the grip needed more, so
the ratio needed falls from 4.0× to 2.9×.

Acceleration and drag speed hardly enter this model (friction is assumed not
to depend on speed), so slowing down is not a fix by itself.

One more effect to measure: when the magnet stops, the piece stops where the
sideways pull falls to the static friction, some distance short of the
magnet's centre. If that distance is more than about 1 mm, the G-code could
overshoot each drag slightly and come back. That would be a software change
and is not done here.

## 8. Rod deflection

| Input | Value | Basis |
|---|---|---|
| Rod | 8 mm, I = π d⁴ ÷ 64 = 201.1 mm⁴ | design |
| Steel modulus E | 200000 N/mm² | assumption |
| Span | 500 mm, simply supported | assumption: the whole rod length, which overstates the sag |
| Magnet spring preload | 2 N | assumption: the top end of a "light" spring |

The spring pushes the magnet up against the board top and pushes the
carriage down by the same amount, so the X rods carry the carriage's weight
plus the preload. The magnet's pull on a piece does not load the rods: the
magnet is already pressed against the top, and the top takes that force. The
Y rods carry the whole gantry plus the preload. Each pair of rods shares its
load equally, and the worst case puts all of it at mid-span.

- point load at mid-span: δ = P L³ ÷ (48 E I)
- the rod's own weight: δ = 5 w L⁴ ÷ (384 E I) = 0.078 mm

| Rods | Load per rod | Sag from the load | With own weight |
|---|---|---|---|
| X (carriage 1.37 N + spring 2 N, ÷ 2) | 1.69 N | 0.109 mm | 0.19 mm |
| Y (gantry 10.25 N + spring 2 N, ÷ 2) | 6.12 N | 0.397 mm | 0.47 mm |

**Conclusion:** at the middle of the board the carriage sits at most 0.66 mm
lower than at the corners. The spring keeps the magnet pressed on the top, so
this does not change the gap. Rod holders that clamp the ends rigidly would
cut the sag from the loads to a quarter (P L³ ÷ (192 E I): 0.027 mm on X,
0.099 mm on Y), though printed holders are not fully rigid. Give the spring at least 3 mm
of working travel; that figure is a judgment, not a calculation, to cover the
frame's flatness and any sag of the board top as well.

## 9. Belt lengths

Each axis has one belt loop: from the moving part, around the motor pulley,
back along the axis, around an idler, and back to the moving part, with both
ends clamped.

loop = 2 × centre distance + 20 teeth × 2 mm (half of each pulley) + 2 × clamp allowance

| Input | Value | Basis |
|---|---|---|
| Centre distance, pulley to idler | 500 mm | assumption: about one rod length (the CAD sets the real figure) |
| Clamp allowance | 30 mm per belt end | assumption |
| Roll | 5000 mm | design (BOM) |

One loop = 2 × 500 + 40 + 2 × 30 = **1100 mm**. X and Y together use 2200 mm,
leaving 2800 mm. If the gantry racks and needs a second Y belt, a third loop
still leaves 1700 mm. The idlers are 20-tooth either way, the belt kit's
5 mm-bore ones in the funded build or the optional 3 mm-bore ones, so the
loop is the same with both.

## 10. Reset job: time and magnet duty

**Method.** The script plans the reset job exactly as
`node demo.js reset --storage 1 --square 40 --size 0.475` does, writes its
G-code with `src/gcode.js`, and runs that G-code through a model of GRBL 1.1's
motion planner:

- `G0` at `$110`/`$111` and `G1` at the programmed feed, each axis limited separately, as GRBL does
- speeds ramp at `$120`/`$121`; corners slow down by GRBL's junction-deviation rule with `$11` = 0.010 mm, and straight runs of segments keep full speed
- `M8`, `M9` and `G4` wait for motion to stop (GRBL empties its buffer for them), so every drag starts and ends at rest
- the magnet starts and ends at `X0 Y0`, the outer corner of the left storage column (offsets of 0)

Not modelled: homing (up to 18.7 s, section 12), delays in streaming
G-code over USB (the sender is assumed to keep GRBL's buffer full), and
GRBL's stepwise speed updates.

The planner's figures: 22 moves, 2397 mm dragged, 2101 mm of empty travel
between moves. The G-code adds the trips out from and back to `X0 Y0`, so it
has 2352 mm of `G0` travel and 2397 mm of `G1` drags.

With `$110` = 6000, `$120` = 400 and `F2000`:

- travel 27.8 s + drags 74.2 s + pauses 8.8 s = **110.8 s (1.8 min)**
- magnet on for 78.6 s, **71%** of the job, 3.57 s per move
- drags average 32.3 mm/s against the 33.3 mm/s set by `F2000`; corners slow them down

| Settings | Travel (s) | Drags (s) | Pauses (s) | Total (s) | Magnet on |
|---|---|---|---|---|---|
| recommended | 27.8 | 74.2 | 8.8 | 110.8 | 71% |
| drag `F1000` | 27.8 | 144.8 | 8.8 | 181.3 | 82% |
| drag `F3000` | 27.8 | 51.7 | 8.8 | 88.3 | 64% |
| `$120` = 800 | 24.9 | 73.0 | 8.8 | 106.6 | 73% |
| `$110` = 10000 | 22.6 | 74.2 | 8.8 | 105.6 | 74% |

**Conclusion:** a reset takes just under two minutes, plus homing. Dragging
is 74.2 s of the 110.8 s, so the drag feed is the only setting that changes
the total much: `F3000` would take 88.3 s, and `F1000`, where Milestone 3 starts
tuning, 181.3 s. Doubling the acceleration saves 4 s and `$110` = 10000
saves 5 s, which is not worth the extra noise. Use the fastest drag feed that
passes the Milestone 3 test.
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

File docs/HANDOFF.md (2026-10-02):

# Handoff: after the design push

The warm-up submission closes **Sunday, October 4 at 11:59 PM**.

## Where things stand (2026-10-01)

The design push is done. The saved workflow
([`.claude/workflows/robotic-chessboard-design-push.js`](../.claude/workflows/robotic-chessboard-design-push.js))
ran all five tracks, each with an independent review and a fix pass:

| Track | Result |
|---|---|
| Gantry and assembly CAD | [cad/](../cad): 16 printed parts, STLs, assembly with fit and reach checks, four renders. `bash cad/export.sh` passes all its checks |
| Wiring schematic | [img/wiring.svg](img/wiring.svg), drawn by `cad/make-wiring.js` |
| Engineering calculations | [CALCULATIONS.md](CALCULATIONS.md), every figure printed by `scripts/calculations.js` |
| G-code sender and calibration | `send.js`, `calibrate.js`, `src/grbl.js`, `src/send-job.js`, `src/calibration.js` |
| Parts list | [BOM.md](BOM.md): every row checked on 2026-10-01 |

The full-spec parts list came to $116.38, so four parts were cut to fit the
$100 tier: the separate 3 mm idlers (the belt kit's 5 mm idlers are used,
and the CAD's idler bore is now a setting), the felt pads, the 5 A adapter
(3 A instead) and the second 45 N·cm motor (a 17HS4401 on X instead). **The
funded list is $98.36 with tax.** The cut parts, plus spares and other
improvements, are in [BOM.md: Add back when building](BOM.md#add-back-when-building),
to be bought separately at build time.

## Open before ordering

1. **Prices that can move** ([BOM.md](BOM.md#prices-that-can-change)): the
   X motor (row 3) and the bearings (row 6) are on sale until Oct 7; the
   fuse holders (row 12) are on sale with no end date shown.
2. **Quantities.** Rows 10 and 13 buy more than one of an AliExpress item;
   the regular price for a second unit wasn't tried in a cart.
3. **Belt kit idlers.** Row 5's two idlers come from the kit's description.
   If they don't arrive, buy the 3 mm idler pack (an add-back) and print the
   two idler parts for 3 mm ([cad/README.md](../cad/README.md#using-3-mm-idlers)).

## Notes

- AliExpress blocks automated visits to its product pages, but its search
  results load. Prices were read from the search page's quick-view panel with
  the variant selected. After many quick-views it starts showing a CAPTCHA.
- The washers must be plain carbon steel. Stainless washers are barely
  magnetic.
- Sales tax in San Jose is 10.000% since 2026-04-01 (Measure A).

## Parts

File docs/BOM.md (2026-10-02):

# Parts list (funded build)

Everything needed for the compact v1 board in [DESIGN.md](DESIGN.md): an XY
gantry that moves an electromagnet under a 400 × 320 mm board top. This is
the list submitted for the $100 tier 3 funding. Four parts were cut or
downgraded to fit the budget; they, and other parts that would improve the
board, are listed under [Add back when building](#add-back-when-building),
to be bought separately at build time. The design works either way.

Prices are in US dollars for a US buyer, and every row was checked on
2026-10-01. Amazon and eBay rows were checked on the product page itself.
AliExpress blocks automated visits to its product pages, so AliExpress rows
were checked in the quick-view panel of its search results, with the exact
variant selected. Each price is the regular price anyone pays; AliExpress's
$1.09 "new shoppers" deals are left out. Three rows are sales that anyone gets
right now (rows 3, 6 and 12); see [Prices that can change](#prices-that-can-change).

**Total: $98.36, which is $1.64 under the $100 tier 3 budget.**

| # | Part | What it's for | Qty | Unit $ | Line $ | Vendor | Link |
|---|---|---|---|---|---|---|---|
| 1 | Arduino Uno R3 + CNC Shield V3 + 4 × A4988 drivers with heatsinks, USB cable (kit) | Uno runs GRBL 1.1; the shield drives both motors, switches the magnet from CoolEn (A3) and reads the X−/Y− endstops | 1 | 7.88 | 7.88 | AliExpress (Realpoy Module Wholesale Store) | https://www.aliexpress.us/item/3256806291794239.html |
| 2 | STEPPERONLINE NEMA 17 stepper, 45 N·cm, 1.5 A, 39 mm body, 1 m cable | Y axis motor (moves the whole gantry); also lifts the Amazon order over $35 so it ships free | 1 | 12.99 | 12.99 | Amazon (sold by StepperOnline) | https://www.amazon.com/dp/B07LF898KN |
| 3 | NEMA 17 stepper 17HS4401, 1.5 A, 40 mm body, with Dupont cable | X axis motor (moves only the magnet carriage) | 1 | 5.25 | 5.25 | AliExpress (JINGLIN 3D Store) | https://www.aliexpress.us/item/3256808478690312.html |
| 4 | Linear rods, 8 mm × 500 mm, case-hardened chrome, pack of 4 | Two Y rods on the base, two X rods on the gantry | 1 | 23.99 | 23.99 | Amazon (sold by Sharp Domain Hardware, ships from Amazon) | https://www.amazon.com/dp/B0C2MJMMQM |
| 5 | GT2 6 mm belt 5 m + 2 × 20T pulleys (5 mm bore) + 2 × 20T idlers (5 mm bore) (kit) | Belts, motor pulleys and the two belt idlers | 1 | 7.67 | 7.67 | AliExpress (KUFAN 3D Printer Store) | https://www.aliexpress.us/item/3256809943699118.html |
| 6 | LM8UU linear ball bearing 8 × 15 × 24 mm, lot of 10 | Gantry end blocks (2 per Y rod) and the magnet carriage (8 used) | 1 | 6.59 | 6.59 | AliExpress (BN-Bearing Store) | https://www.aliexpress.us/item/3256808328579983.html |
| 7 | 12 V holding electromagnet HCNE1-P20/15 (20 × 15 mm, M3 thread, 3 W) | Grabs the steel washer in each piece through the board top | 1 | 3.95 | 3.95 | AliExpress (Hardware appliances store) | https://www.aliexpress.us/item/3256807419633345.html |
| 8 | MOSFET trigger switch module, 15 A 400 W, DC 5–36 V | Switches the magnet from GRBL's CoolEn pin: `M8` on, `M9` off | 1 | 2.03 | 2.03 | AliExpress (Jujiasheng Electronics store) | https://www.aliexpress.us/item/3256809498020632.html |
| 9 | 1N5819 Schottky diode, 1 A 40 V, DO-41, lot of 100 | Flyback diode across the magnet coil (1 used) | 1 | 2.07 | 2.07 | AliExpress (InShop Chip Store) | https://www.aliexpress.us/item/2251832821661353.html |
| 10 | Mechanical endstop switch board with cable (RAMPS style) | Homing switches on X and Y | 2 | 1.72 | 3.44 | AliExpress (YX Electronic Components) | https://www.aliexpress.us/item/3256809234716436.html |
| 11 | 12 V 3 A AC/DC adapter, US plug | Powers the motors (through the shield) and the magnet | 1 | 2.66 | 2.66 | AliExpress (GBKOF LED Factory Store) | https://www.aliexpress.us/item/3256808383701455.html |
| 12 | Inline 5 × 20 mm glass fuse holder with 22 AWG leads and 5 A fuses, 5 sets | Fuse on the +12 V line, before everything else | 1 | 2.45 | 2.45 | AliExpress (Choice listing) | https://www.aliexpress.us/item/3256807619256072.html |
| 13 | M8 flat washer, zinc-plated carbon steel, lot of 10 | Steel insert in each of the 34 piece bases | 4 | 1.31 | 5.24 | AliExpress (MSLPJ Store) | https://www.aliexpress.us/item/3256803033699156.html |
| 14 | PTFE-coated fiberglass tape, 0.13 mm thick, 10 mm wide, 10 m | Low-friction face on the magnet where it slides against the board top | 1 | 2.91 | 2.91 | AliExpress (The Nineteenth Century Store) | https://www.aliexpress.us/item/3256810401333660.html |
| | **Parts** | | | | **89.12** | | |
| | **Tax and shipping (estimate)** | $8.91 sales tax at 10.000% + $0.33 shipping | | | **9.24** | | |
| | **Total** | | | | **98.36** | | |

## Notes per row

Pick the variant named here; most listings open on a different one.

1. Variant "A4988 Green Kit". The listing photo shows the Uno, USB cable,
   shield, four drivers and heatsinks. The USB chip isn't named; it is most
   likely a CH340, which needs the CH340 driver on some computers. Only two of
   the four drivers are used.
2. "Number of Items: 1". The page lists 17HS15-1504S-X1, 45 N·cm, 1.5 A.
   It goes on the Y axis, which moves the whole gantry, X motor included.
   Amazon ships free only when Amazon-shipped items total $35 or more, so keep
   this motor and the rods (row 4) in the same order ($36.98).
3. Variants "1PCS" and "17HS4401 Dupont". It goes on the X axis, where it
   rides on the gantry: the CAD allows a body up to 51 mm long.
   [CALCULATIONS.md](CALCULATIONS.md) sizes the X axis from this motor's
   listing and finds about 3× torque margin.
   $5.25 is a sale price, one per shopper, ending Oct 7; the regular price is
   $12.38. The variant name suggests a cable with a Dupont plug that fits the
   shield's motor pins, but the listing wasn't checked for what the cable
   includes.
4. Size "D 8mm x L 500mm 4 PCS" (the page also offers 400 mm). Free delivery
   was estimated Oct 19 to Nov 13.
5. Variant "20PCS DIY KIT". Free shipping. About 2.2 m of the 5 m belt is
   used. The two idlers (5 mm bore) come from the kit's description as read in
   research; the quick view didn't list the kit's contents. The CAD is drawn
   for them by default (M5 axles). If the kit arrives without idlers, buy the
   3 mm idlers under [Add back when building](#add-back-when-building) and
   print the two idler parts for 3 mm
   ([cad/README.md: Using 3 mm idlers](../cad/README.md#using-3-mm-idlers)).
6. Variant "Lm8uu". $6.59 is a store sale ending Oct 7 (regular $7.94), and
   this is the only row that charges shipping ($0.33).
7. Variants "Voltage: 12V" and "P20-15". It screws onto the M3 guide screw in
   the carriage ([cad/README.md](../cad/README.md)).
8. Variant "1pcs MOSFET Trigger". This is the common dual-MOSFET module
   (VIN+/VIN−, OUT+/OUT−, TRIG/PWM and GND), triggered by 3.3–20 V, so the
   Arduino's 5 V turns it fully on. Check that the chips are marked D4184.
   It has no flyback diode of its own, so row 9 is required.
9. Only one diode is used; the lot is the cheapest way to buy it.
10. Variant "1PCS", quantity 2. The quick view showed "Max. 1 pcs/shopper",
    which is the new-shopper limit; buying two at the regular price wasn't
    tried in a cart. If the cart refuses, the 6PCS variant is $4.70. Wire
    them as the [schematic](img/wiring.png) shows: S to X−/Y−, − to the pin
    beside it, + not connected. The CAD models a 40 × 16 mm board with holes
    35 mm apart; measure yours before printing the mounts.
11. Variants "US Plug", "12V", "3A". No-name adapter, not UL listed. The
    machine is estimated to draw about 0.87 A, a 3.4× margin; the worst-case
    bound, every coil at full current at once, is 3.22 A
    ([CALCULATIONS.md §11](CALCULATIONS.md#11-power-budget-and-magnet-heat)).
    Measure the draw while homing and moving in Milestone 2, and during the
    reset job with the magnet in Milestone 3. The 5 A variant of the same
    listing is an add-back. If you cut off the
    barrel plug, find +12 V with a meter before connecting anything: the
    shield has no reverse-polarity protection.
12. Variant "AMP: 5A". $2.45 is a sale (list price $5.22); the end date isn't
    shown. The 5 A fuse stays with either adapter. The 22 AWG leads are thin
    for 5 A, so keep them short.
13. Variant "10pcs M8", quantity 4 (40 washers for 34 pieces). Zinc-plated
    carbon steel is magnetic. **Never use stainless washers**: they are barely
    magnetic. The listing doesn't state the outer diameter. A standard M8
    washer is 16 mm and the pocket in [cad/pieces.scad](../cad/pieces.scad) is
    16.4 mm, so measure one when they arrive. The quantity note from row 10
    applies here too.
14. Variant "10mm Width-10M-Roll". Lay two strips side by side to cover the
    magnet's 20 mm face.

## Tax and shipping

This is an estimate; no cart or checkout was opened.

- **Sales tax: $8.91.** That is 10.000% of $89.12, San Jose's rate since
  Measure A took effect on 2026-04-01. Elsewhere in Santa Clara County the
  rate is 9.75% ($8.69). AliExpress, Amazon and eBay all collect California
  sales tax.
- **Shipping: $0.33**, on row 6 only. The other AliExpress rows showed free
  shipping, and Amazon ships free because rows 2 and 4 total $36.98.
- **Import charges:** none were shown. If AliExpress adds any at checkout,
  add a few dollars.

The order splits two ways: AliExpress $52.14 (12 rows) and Amazon $36.98.

## Prices that can change

- **Row 3 (X motor):** $5.25 is a sale, one per shopper, ending Oct 7. At its
  regular $12.38 the total would be $106.21.
- **Row 6 (bearings):** sale until Oct 7; regular $7.94 (+$1.49 with tax).
- **Row 12 (fuse holders):** sale with no end date shown; list $5.22
  (+$3.05 with tax).
- **Rows 10 and 13:** more than one of the same AliExpress item; the price of
  the second unit wasn't tried in a cart.

## What was cut to fit the budget

The full-spec list came to $116.38. These four changes bring it to $98.36:

| Change | Saves (with tax) | Effect on the build |
|---|---|---|
| The belt kit's two 5 mm-bore idlers replace a separate pack of 3 mm-bore idlers | $6.80 | None: the CAD's idler bore is a setting, 5 mm by default, with M5 axles |
| No felt pads under the pieces | $2.17 | Pieces slide on their printed bases. Less gap means more grip ([CALCULATIONS.md §7](CALCULATIONS.md#7-grip-does-the-piece-follow-the-magnet)); Milestone 1 decides whether felt is worth adding |
| 12 V 3 A adapter instead of 5 A | $3.28 | Less headroom; see row 11 |
| A 17HS4401 on X instead of a second STEPPERONLINE 45 N·cm motor | $5.78 | 40 N·cm instead of 45 on the X axis, which moves only the light carriage. The calculations size each axis from its own motor's listing: about 3× torque margin on both |

## Add back when building

Not part of the funding request: parts to buy separately at build time,
because they make the board better or back up a risky part. Prices were seen
on 2026-10-01 where given; check them again when ordering.

| Part | Why add it | Price seen | Link | What changes |
|---|---|---|---|---|
| GT2 20T toothed idlers, 3 mm bore, pack of 4 (variant "20T W6 B3 With T", "4pcs") | Only if the belt kit arrives without idlers, or as spares | $6.18 | https://www.aliexpress.us/item/3256807370977153.html | Print the idler end block and the Y idler mount for 3 mm ([cad/README.md: Using 3 mm idlers](../cad/README.md#using-3-mm-idlers)); M3 axles instead of M5 |
| Self-adhesive felt circles, 20 mm, 48 (variant "Black 20mm 48pcs") | Quieter moves, protects the board sheet, steadier sliding if bare PLA or the washer scuffs or sticks | $1.97 | https://www.aliexpress.us/item/3256811410708037.html | Trim each to about 18 mm. It adds about 1 mm to the magnet gap, which weakens the pull ([CALCULATIONS.md §7](CALCULATIONS.md#7-grip-does-the-piece-follow-the-magnet)), so let Milestone 1 decide |
| 12 V 5 A adapter (variant "US Plug", "12V", "5A" of row 11) | Headroom above the 3.22 A worst-case bound; the estimated draw is 0.87 A, so this is insurance rather than a need | $5.64 | https://www.aliexpress.us/item/3256808383701455.html | Nothing; same wiring and fuse |
| Second STEPPERONLINE 45 N·cm motor | A matched pair, more torque on X | $10.50 (eBay, showed "Last one") or $12.99 (Amazon, row 2) | https://www.ebay.com/itm/264814082447 | Nothing; it is 39 mm long, under the X motor's 51 mm limit |
| Spare MOSFET modules (variant "5pcs MOSFET Trigger" of row 8) | Spares for the part most likely to be damaged by a wiring mistake | $3.68 | https://www.aliexpress.us/item/3256809498020632.html | Nothing |
| Spare P20/15 electromagnet (row 7) | Grip is the biggest risk, and Milestone 1 tests the magnet before anything else; a second one also lets you compare | $3.95 | https://www.aliexpress.us/item/3256807419633345.html | Nothing |
| Female DC barrel jack to screw terminal adapter, 5.5 × 2.1 mm | Wires the adapter without cutting its plug, with + and − marked: avoids reversed polarity | not checked | | Nothing |

A stronger magnet (for example a P25/20) is the usual fix if Milestone 1
shows the P20/15 can't drag a king, but the carriage's sleeve and spring are
drawn for a 20 × 15 mm magnet and would have to be redrawn.

## Already on hand (not funded)

- Access to a 3D printer and about 320 g of PLA: about 260 g for the gantry
  parts ([cad/README.md](../cad/README.md)) and about 60 g for the 34 pieces
  ([cad/pieces.scad](../cad/pieces.scad))
- A plywood or MDF base about 600 × 500 mm, a 3 mm hardboard (smooth on both
  sides) or MDF sheet for the board top, and wood strips for the frame walls
- Screws: M3 screws and nuts, including 12 grub screws, 9 countersunk
  M3 × 10 and an M3 × 25 guide screw for the magnet; for the idler axles an
  M5 × 30 and an M5 × 20 socket screw, 2 M5 nuts and 4 M5 washers; about 19
  wood screws (the hardware table in [cad/README.md](../cad/README.md) has
  the full list)
- A light spring for the magnet carriage, for example from a retractable
  ballpoint pen (about 5–6 mm across and 20 mm long)
- Hookup wire (18–22 AWG), zip ties, a soldering iron and solder
- Superglue or epoxy to fix the washers into the piece bases
- A multimeter, to set each A4988's current limit, find the adapter's +12 V
  and measure the machine's current draw
- A computer or Raspberry Pi (a USB cable comes with row 1)
- Paper and a printer for the board sheet ([cad/board-sheet.svg](../cad/board-sheet.svg))

## Upgrades later (not in this budget)

| Upgrade | Why |
|---|---|
| TMC2209 drivers instead of A4988 | Nearly silent motors |
| 2020 aluminium extrusion frame | Stiffer, easier to square up |
| 50 mm squares, two storage columns per side | Bigger pieces, room for every captured piece |
| Reed switches or Hall sensors under every square | Detect moves made by hand (Milestone 5 in the roadmap) |

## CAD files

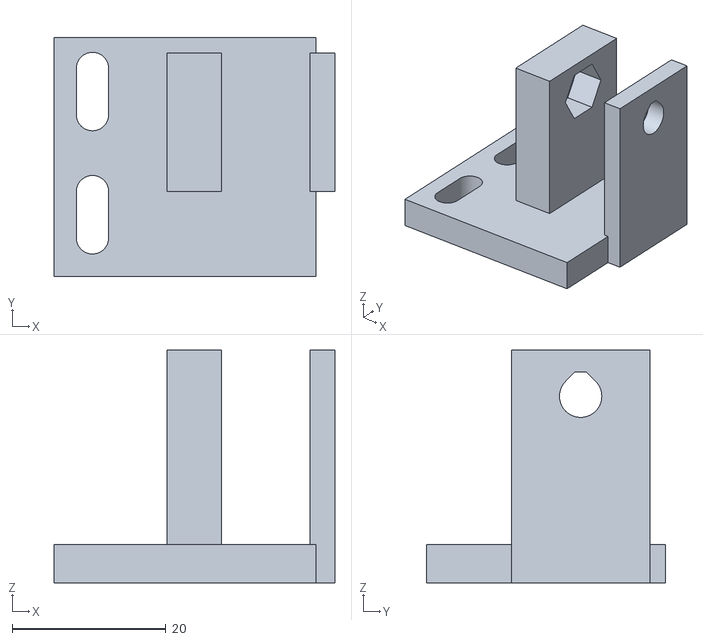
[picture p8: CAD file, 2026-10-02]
cad/stl/y-idler-mount.stl
36.5 x 31.0 x 30.2

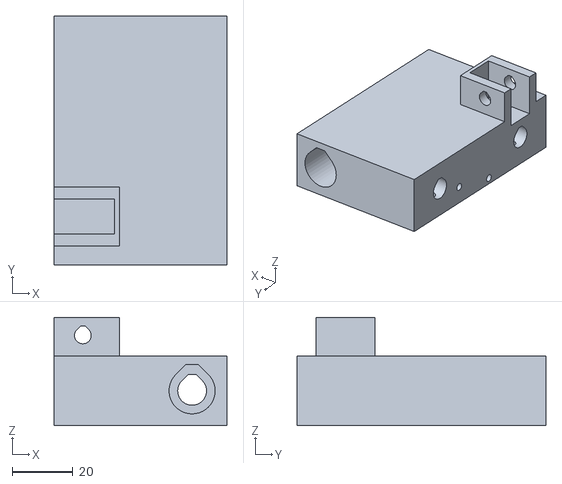
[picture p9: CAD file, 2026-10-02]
cad/stl/end-block-idler.stl
57.0 x 82.0 x 35.7

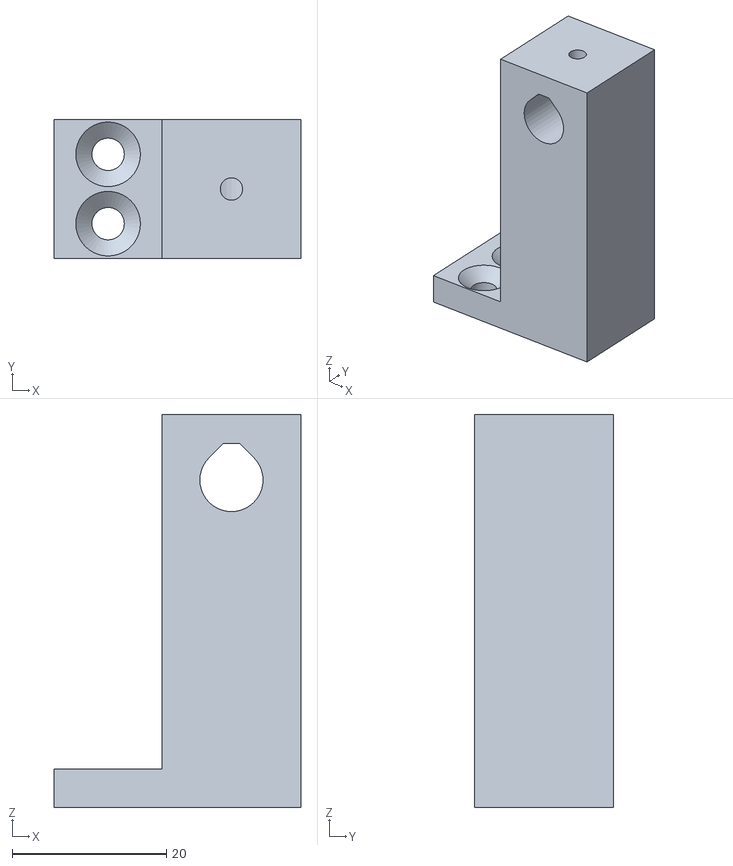
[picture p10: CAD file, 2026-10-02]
cad/stl/y-rod-holder.stl
32.0 x 18.0 x 51.0

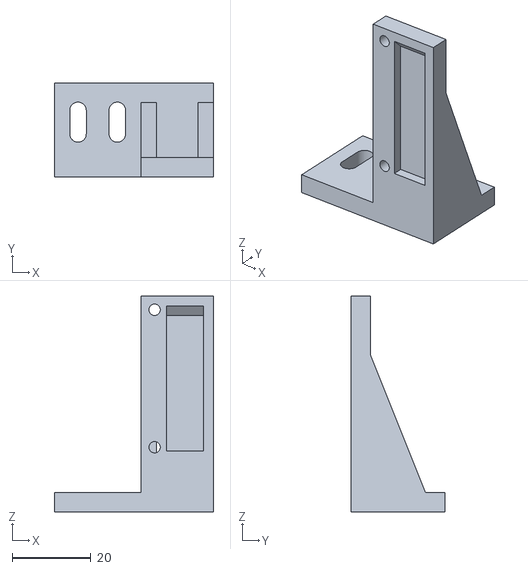
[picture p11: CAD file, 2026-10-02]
cad/stl/y-endstop-mount.stl
40.5 x 24.0 x 55.0

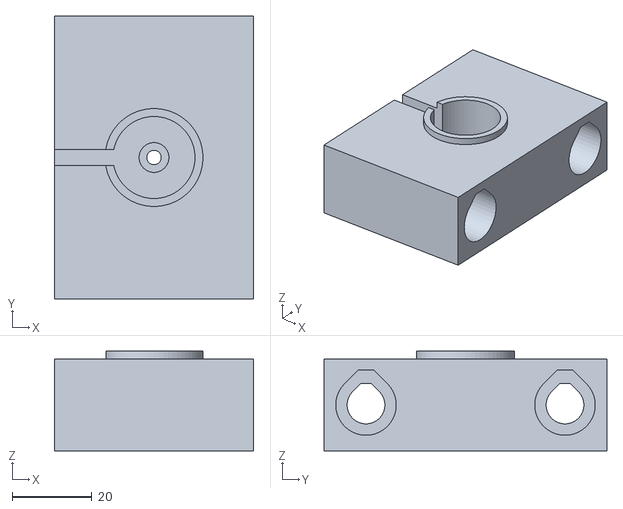
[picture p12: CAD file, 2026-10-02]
cad/stl/carriage.stl
50.0 x 71.0 x 25.0

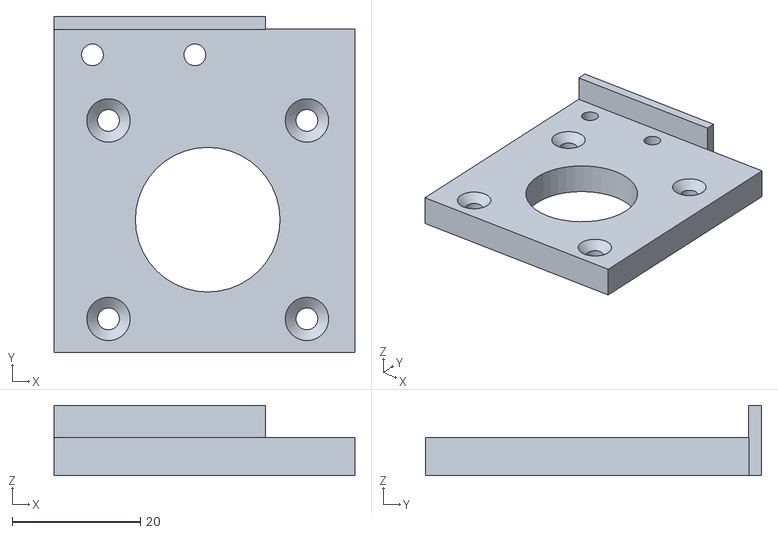
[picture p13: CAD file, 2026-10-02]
cad/stl/x-motor-mount.stl
47.0 x 52.5 x 11.0

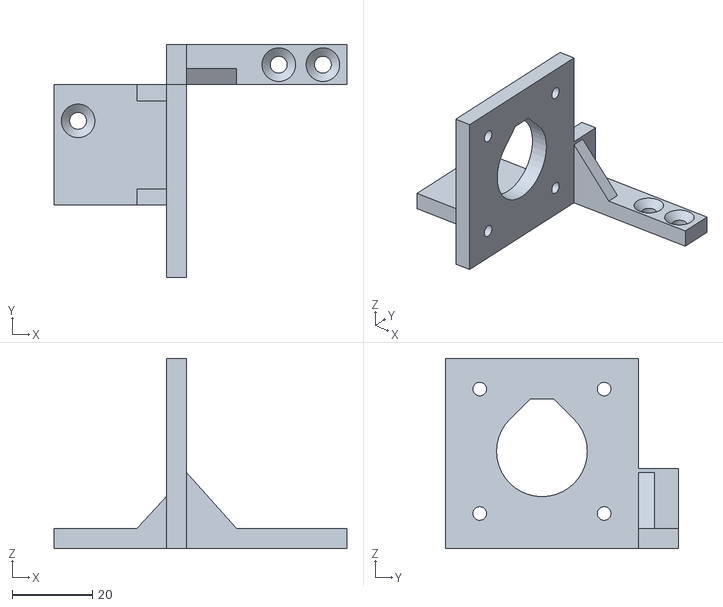
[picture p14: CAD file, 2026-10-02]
cad/stl/y-motor-mount.stl
73.0 x 58.0 x 47.4

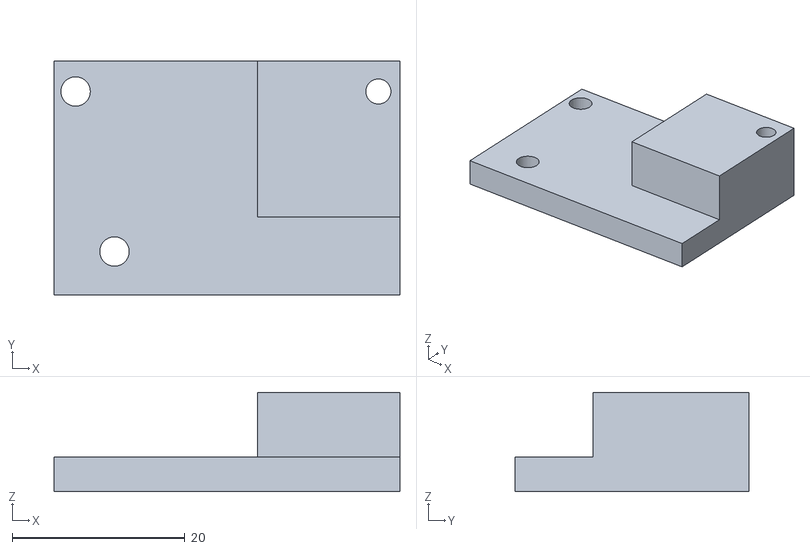
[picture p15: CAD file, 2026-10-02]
cad/stl/x-endstop-mount.stl
40.0 x 27.0 x 11.5

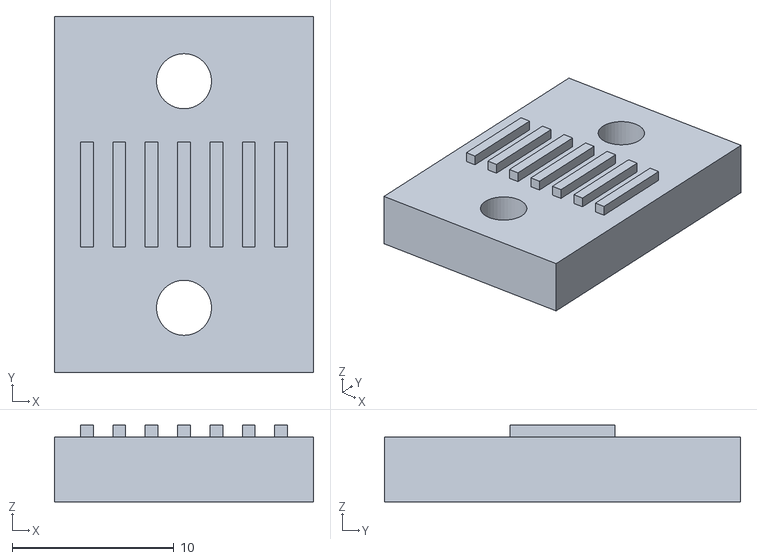
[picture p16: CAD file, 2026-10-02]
cad/stl/belt-clamp.stl
16.0 x 22.0 x 4.74

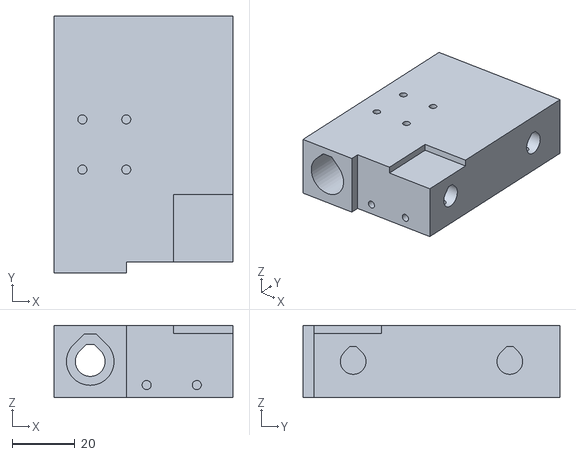
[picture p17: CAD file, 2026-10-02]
cad/stl/end-block-motor.stl
57.0 x 82.0 x 23.0

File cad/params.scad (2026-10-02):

// Shared dimensions for the gantry, its printed parts and the assembly.
//
// Units are millimetres. Machine coordinates: the origin is the front-left
// corner of the base's top surface, X runs to the right along the board's
// 10-cell direction, Y runs away from you along the 8 ranks, Z is up.
// Parts that ride on the X gantry are drawn in "gantry Y": 0 is the line
// through the magnet, so they sit at gantry_y + y in machine coordinates.
//
// Included by gantry-parts.scad and assembly.scad. Change a number here and
// both follow. Values marked "estimate" were not checked against a real
// part; measure yours before printing.

// ---------- Board grid (matches cad/make-board.js and src/gcode.js) ----------
square = 40;
storage_cols = 1;
grid_cols = 8 + 2 * storage_cols; // 10 cells across, storage included
grid_rows = 8;
sheet_w = grid_cols * square;     // 400: printed surface, X
sheet_d = grid_rows * square;     // 320: printed surface, Y
reach_x = sheet_w - square;       // 360: between the outermost cell centres
reach_y = sheet_d - square;       // 280
min_margin = 5;                   // travel required beyond the outermost centres

// ---------- Base, frame and top ----------
base_w = 600;
base_d = 500;
base_t = 12;      // plywood or MDF
wall_t = 12;      // frame walls, screwed to the outside edges of the base
top_t = 3;        // hardboard top
sag_allow = 3;    // how far the middle of the top may sit below its edges

// ---------- Fasteners and printing ----------
m3_clear = 3.4;   // M3 clearance hole
m3_tap = 2.9;     // pilot hole an M3 screw cuts its own thread into
m3_head_d = 5.5;  // M3 socket head
m3_head_h = 3;
m3_nut_af = 5.5;  // across flats
m3_nut_h = 2.4;
wood_clear = 4.2; // 3.5-4 mm wood screw
wood_head_d = 8.4;
fit = 0.5;        // general clearance between printed parts and bought parts

// ---------- Smooth rods and LM8UU bearings ----------
rod_d = 8;
rod_len = 500;    // all four rods, uncut
rod_hole = 8.2;   // rod clearance (holders and sockets, locked by set screws)
grub_in = 8;      // X rod grub screws: one this far from the rod end ...
grub_out = 4;     // ... and one this far from the socket mouth
lm_d = 15;
lm_len = 24;
lm_bore = 15.2;   // press fit for the LM8UU
lm_stop_d = 9.5;  // shoulder between two bearings pressed in from each end;
                  // leaves 1 mm of plastic over the Y belt clamp pilot holes
lm_wall_below = 3.9; // plastic under a bearing bore (room for clamp screws)

// ---------- NEMA 17 stepper ----------
nema_w = 42.3;
nema_len = 48;    // longest common body; 40 mm motors fit with more room
nema_pitch = 31;  // M3 hole square
nema_boss_d = 22;
nema_boss_h = 2;
nema_boss_hole = 22.6;
nema_shaft_d = 5;
nema_shaft_len = 24;

// ---------- GT2 belt, 20T pulley, 20T idler ----------
belt_w = 6;
belt_back = 0.63;      // belt backing outside the pulley's tooth tips
belt_tooth = 0.75;     // tooth height
pulley_tip_d = 12.22;  // 20T tooth-tip diameter (pitch diameter 12.73)
pulley_flange_d = 16;
pulley_len = 16;
pulley_hub_len = 7;    // estimate
pulley_teeth_len = 9;  // toothed part, flanges included, estimate
pulley_off = 4.5;      // pulley end (flange) to the belt line, along the shaft
// 20T toothed idler, the same outside size with a 3 mm or a 5 mm bore. Drawn
// from one seller's drawing of the 5 mm one; Motedis lists a 20T 5 mm-bore
// idler as 18 mm across and 9 mm long, so the slots are sized for idler_w_max.
// Measure yours: if it is wider than idler_w_max, set both widths to it and
// run the checks (cad/README.md, Hardware).
idler_d = 18;          // across the flanges
idler_w = 8.5;         // overall width, as drawn
idler_w_max = 9;       // the widest idler the slots take
idler_gap = 6.5;       // between the flanges
idler_tip_d = 12.2;    // across the teeth

// ---------- Idler axles ----------
// Which idlers the build uses, and so the screws they turn on:
//   5 = the two 20T idlers that come in the GT2 belt kit (5 mm bore), on M5
//       axles. The funded build and the default.
//   3 = separate 20T idlers with a 3 mm bore (an optional add-back), on M3
//       axles.
// Only end-block-idler and y-idler-mount change. Export them with
// -D idler_bore=3 ("Using 3 mm idlers" in cad/README.md has the commands).
idler_bore = 5;
assert(idler_bore == 5 || idler_bore == 3,
  str("idler_bore must be 5 (the belt kit's idlers, M5 axles) or 3 (separate 3 mm-bore idlers, M3 axles), not ", idler_bore));
axle_m5 = idler_bore == 5;
axle_d = idler_bore;                       // screw: M5 or M3
axle_clear = axle_m5 ? 5.5 : m3_clear;     // clearance hole
// Hex nut across flats, and the thickest nut the parts are drawn for: ISO 4032
// allows M5 nuts 4.4-4.7 mm thick and M3 nuts 2.15-2.4 mm; the older DIN 934
// M5 nut is 3.7-4 mm (fasten.it's tables for both standards).
axle_nut_af = axle_m5 ? 8 : m3_nut_af;
axle_nut_h = axle_m5 ? 4.7 : m3_nut_h;
axle_washer_t = axle_m5 ? 1 : 0.5;         // flat washer (DIN 125), one each side of each idler
axle_washer_d = axle_m5 ? 10 : 7;
axle_head_d = axle_m5 ? 8.5 : m3_head_d;   // socket head cap screw (ISO 4762)
axle_head_h = axle_m5 ? 5 : m3_head_h;
x_axle_len = axle_m5 ? 30 : 25;            // X idler: M5 x 30 or M3 x 25, nut on the back face
y_axle_len = axle_m5 ? 20 : 18;            // Y idler: M5 x 20 or M3 x 18, nut in a pocket
nut_pocket = axle_nut_h + 0.4;             // the Y idler mount's nut pocket: depth ...
nut_pocket_d = axle_nut_af / cos(30) + 0.3; // ... and size across the corners
idler_slot = idler_w_max + 2 * axle_washer_t + 0.5; // the widest idler, a washer each side and 0.5 mm play
idler_cheek = 4;       // each cheek of the foot that carries the X idler
idler_foot_down = 6;   // that foot reaches this far below the X idler's axle

// ---------- Electromagnet (P20/15) and its spring ----------
mag_d = 20;
mag_h = 15;
mag_thread_engage = 5; // how far the M3 guide screw goes into the magnet (measure yours)
sleeve_id = mag_d + 0.6;
sleeve_wall = 2;
floor_t = 4;           // carriage floor under the magnet
spring_pocket_d = 7.5; // seats a spring up to 7 mm across
spring_pocket_h = 2;
spring_free = 20;      // free length of the spring this is drawn for (estimate)
spring_od = 6;
guide_screw_len = 25;  // M3 x 25: guide pin and up-stop for the magnet

// ---------- Mechanical endstop module (RepRap style PCB) ----------
// Drawn as the "Mechanical Endstop v1.1" datasheet board: 40 x 16 mm, the
// switch at one end, the 3-pin connector at the other, two holes along one
// long edge. One shop lists the v1.2 board as 36.5 x 16 x 10 mm overall, and
// clones differ, so measure yours. Both switches stand on end with the
// connector at the bottom, below the part that presses the lever, so the plug
// stays clear whatever its height. Heights are off the PCB's component side.
es_pcb = [40, 16, 1.6];  // long side, short side, thickness
es_hole_inset = 2.5;
es_hole_span = 35;
es_body = 6.5;     // switch body height, estimate
es_trigger = 8;    // lever height where the switch trips, estimate
es_lever = 10;     // free lever height, estimate
es_conn = [6, 10, 18]; // connector with its plug: along the board, across it, height (generous estimate)
es_relief = 2.5;   // pocket behind the PCB for its solder pins

// ---------- Heights (Z) ----------
z_shaft = 24.25;                                  // every pulley and idler axis
belt_top = z_shaft + pulley_tip_d / 2 + belt_back; // 31.0: back of the upper belt run
z_flat = belt_top;                                // flat underside of carriage and end blocks
z_rod = z_flat + lm_wall_below + lm_bore / 2;     // 42.5: all four rods
z_parts_top = z_rod + 11.5;                       // 54: top of carriage and end blocks
z_board = 61;                                     // underside of the 3 mm top
sleeve_top = z_board - 5;                         // rim of the magnet sleeve
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

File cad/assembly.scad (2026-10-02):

// The whole machine: base, rods, gantry, carriage, magnet, motors, belts,
// frame and the 3 mm top, with checks that it fits together (OpenSCAD).
//
// Bought parts (motors, bearings, pulleys, magnet, switches) are simple
// stand-ins drawn to their catalogue sizes. Printed parts come from
// gantry-parts.scad. Coordinates are explained in params.scad.
//
//   openscad assembly.scad                      magnet under cell (0, 0)
//   openscad -D cell_x=9 -D cell_y=7 assembly.scad
//   openscad -D 'view="section"' assembly.scad  cut through the magnet
//   openscad -D 'view="top"' -D labels=true assembly.scad
//   openscad -D 'check="collide"' -o out.stl assembly.scad
//       renders only the overlaps between moving and fixed parts at the
//       four corners of travel; OpenSCAD reports an empty object if none.
// cad/export.sh has the camera settings used for the pictures in docs/img.
//
// The echo() lines at the end print the reach, clearance and travel checks.
// Cables are not modelled, so nothing here checks them.

include <params.scad>
use <gantry-parts.scad>

cell_x = 0;            // 0..9 from the left storage column
cell_y = 0;            // 0..7 from rank 1
view = "assembly";     // "assembly", "top" or "section"
show_top = true;       // the 3 mm top and its printed sheet
top_alpha = 0.22;      // see-through so the gantry shows
sheet_alpha = 0.9;     // the printed board sheet
walls = "back";        // "all", "back" (front and side walls left off) or "none"
labels = false;        // text labels for the section and top views
show_base = true;      // false to look at the gantry from below
check = "none";        // "collide": render only interferences
check_push = 0;        // mm to push the gantry past its front stop (test the test)
$fn = 32;

// ---------- Where the board sits ----------
// Where GRBL's soft limits let the magnet go after homing (machine zero is
// where the switch trips; see params.scad), then the printed sheet centred
// on that window.
soft_x0 = x_home - grbl_x;
soft_x1 = x_home;
soft_y0 = y_home - grbl_y;
soft_y1 = y_home;
sheet_x0 = (soft_x0 + soft_x1) / 2 - sheet_w / 2;
sheet_y0 = (soft_y0 + soft_y1) / 2 - sheet_d / 2;

function cell_cx(i) = sheet_x0 + (i + 0.5) * square;
function cell_cy(j) = sheet_y0 + (j + 0.5) * square;

mx = cell_cx(cell_x);  // magnet axis X = carriage X
my = cell_cy(cell_y);  // magnet axis Y = gantry Y

clamp_bottom = belt_top - belt_back - belt_tooth - clamp_t;  // underside of every belt clamp

// ---------- Colours ----------
c_print = "#e8743b";   // printed parts
c_print2 = "#f2a541";  // small printed parts
c_steel = "#b8bec6";
c_dark = "#3b3f45";
c_belt = "#1f1f1f";
c_wood = "#d8b98a";
c_top = "#c9a877";
c_pcb = "#2f6db5";

// ---------- Section cut ----------
// In the section view everything is cut on the plane x = mx (through the
// magnet) and only a 70 mm slab behind it is kept, seen from +X. OpenSCAD's
// preview paints every cut face one colour, so the true section is drawn
// on top as thin coloured 2D slices (projection with cut = true).
// c = undef keeps the children's own colours (outside the section view).
module part_color(c, a = 1) {
  if (view == "section") {
    cc = c == undef ? c_pcb : c;
    color(cc, a) intersection() {
      children();
      translate([mx - 70, -2000, -2000]) cube([70, 4000, 4000]);
    }
    color(cc, a) translate([mx + 0.3, 0, 0]) rotate([0, -90, 0]) linear_extrude(0.3)
      projection(cut = true) rotate([0, 90, 0]) translate([-mx, 0, 0]) children();
  } else if (c == undef) children();
  else color(c, a) children();
}

// ---------- Stand-ins for bought parts ----------

// NEMA 17: mounting face at z = 0, body toward -Z, shaft toward +Z.
module nema17() {
  color(c_dark) translate([0, 0, -nema_len])
    linear_extrude(nema_len) offset(r = 3) square(nema_w - 6, center = true);
  color(c_steel) translate([-nema_w / 2 + 0.5, -nema_w / 2 + 0.5, -8]) cube([nema_w - 1, nema_w - 1, 8]);
  color(c_steel) cylinder(d = nema_boss_d, h = nema_boss_h);
  color(c_steel) cylinder(d = nema_shaft_d, h = nema_shaft_len);
}

// GT2 20T pulley: toothed part from z = 0 to 9 between flanges, hub after it.
module pulley() {
  color(c_steel) {
    cylinder(d = pulley_flange_d, h = 1);
    cylinder(d = pulley_tip_d, h = pulley_teeth_len);
    translate([0, 0, pulley_teeth_len - 1]) cylinder(d = pulley_flange_d, h = 1);
    translate([0, 0, pulley_teeth_len]) cylinder(d = 13, h = pulley_hub_len);
  }
}

// GT2 20T toothed idler, centred on its axis, with the bore idler_bore picks.
module idler() {
  fl = (idler_w - idler_gap) / 2;   // each flange
  color(c_steel) translate([0, 0, -idler_w / 2]) difference() {
    union() {
      cylinder(d = idler_d, h = fl);
      cylinder(d = idler_tip_d, h = idler_w);
      translate([0, 0, idler_w - fl]) cylinder(d = idler_d, h = fl);
    }
    translate([0, 0, -1]) cylinder(d = idler_bore, h = idler_w + 2);
  }
}

// Idler axle hardware (M5 or M3, from idler_bore): a socket head screw with
// its head at z = 0 (head below) and the shank up to z = len, a hex nut and
// a flat washer, both from z = 0 up.
module axle_screw(len) {
  color(c_dark) {
    translate([0, 0, -axle_head_h]) cylinder(d = axle_head_d, h = axle_head_h);
    cylinder(d = axle_d, h = len);
  }
}
module axle_nut() {
  color(c_steel) difference() {
    rotate(30) cylinder(d = axle_nut_af / cos(30), h = axle_nut_h, $fn = 6);
    translate([0, 0, -1]) cylinder(d = axle_d, h = axle_nut_h + 2);
  }
}
module axle_washer() {
  color(c_steel) difference() {
    cylinder(d = axle_washer_d, h = axle_washer_t);
    translate([0, 0, -1]) cylinder(d = axle_d + 0.3, h = axle_washer_t + 2);
  }
}

// The X idler on its axle: head on the foot's front face, nut on its back
// face. Gantry coordinates.
xi_front = xbelt_y - idler_slot / 2 - idler_cheek;   // foot faces, gantry y
xi_back = xbelt_y + idler_slot / 2 + idler_cheek;
module x_idler_axle() {
  translate([x_idler, xi_front, z_shaft]) rotate([-90, 0, 0]) axle_screw(x_axle_len);
  translate([x_idler, xi_back, z_shaft]) rotate([-90, 0, 0]) axle_nut();
  for (s = [-1, 1]) translate([x_idler, xbelt_y + s * (idler_w / 2 + axle_washer_t / 2), z_shaft])
    rotate([-90, 0, 0]) translate([0, 0, -axle_washer_t / 2]) axle_washer();
}

// The Y idler's axle in its mount (at the front stop): head on the outboard
// face, nut pulled against the bottom of its pocket. Machine coordinates.
yi_x_in = ybelt_x - idler_slot / 2;    // inside faces of the mount's cheeks
yi_x_out = ybelt_x + idler_slot / 2;
module y_idler_axle() {
  translate([yim_out_face, yidler_y, z_shaft]) rotate([0, 90, 0]) axle_screw(y_axle_len);
  translate([yi_x_in - nut_pocket, yidler_y, z_shaft]) rotate([0, 90, 0]) axle_nut();
  for (s = [-1, 1]) translate([ybelt_x + s * (idler_w / 2 + axle_washer_t / 2), yidler_y, z_shaft])
    rotate([0, 90, 0]) translate([0, 0, -axle_washer_t / 2]) axle_washer();
}

// LM8UU linear bearing centred on its axis (along Z).
module lm8uu() {
  color(c_steel) difference() {
    cylinder(d = lm_d, h = lm_len, center = true);
    cylinder(d = rod_d + 0.2, h = lm_len + 1, center = true);
    for (s = [-1, 1]) translate([0, 0, s * 8]) difference() {
      cylinder(d = lm_d + 1, h = 1.1, center = true);
      cylinder(d = lm_d - 0.6, h = 2, center = true);
    }
  }
}

// P20/15 holding magnet: face (pole side) up at z = 0.
module magnet() {
  color("#8b9097") translate([0, 0, -mag_h]) cylinder(d = mag_d, h = mag_h);
  color("#e8e8e8") translate([0, 0, -0.1]) cylinder(d = mag_d - 0.5, h = 0.1);  // PTFE tape
  color("#c0392b") for (s = [-1, 1]) translate([s * 5, 0, -mag_h - 4]) cylinder(d = 1.2, h = 4);
}

// Compression spring between z = 0 and z = len.
module spring(len) {
  n = 7;
  color("#d4d8dc") for (i = [0 : n]) translate([0, 0, 0.4 + i * (len - 0.8) / n])
    rotate_extrude($fn = 24) translate([(spring_od - 0.5) / 2, 0]) circle(d = 0.5, $fn = 8);
}

// M3 screw with its head at z = 0 (head below), shank up to z = len + 3.
module m3_screw(len) {
  color(c_dark) {
    translate([0, 0, -m3_head_h]) cylinder(d = m3_head_d, h = m3_head_h);
    cylinder(d = 3, h = len);
  }
}

// Endstop module stand-in, built facing +Z with the PCB's back at z = 0 and
// its long side along X: the switch near the far end, the connector (with a
// plug in it) at the near end. These boxes are also used for the checks.
es_lb_body = [[es_pcb[0] - 18, 3, es_pcb[2]], [es_pcb[0] - 5, 9, es_pcb[2] + es_body]];
es_lb_conn = [[1, (es_pcb[1] - es_conn[1]) / 2, es_pcb[2]], [1 + es_conn[0], (es_pcb[1] + es_conn[1]) / 2, es_pcb[2] + es_conn[2]]];
module box(b) { translate(b[0]) cube(b[1] - b[0]); }
module endstop_module() {
  color(c_pcb) cube(es_pcb);
  color(c_dark) box(es_lb_body);
  color(c_steel) translate([es_pcb[0] - 20, 3, es_pcb[2] + es_lever]) cube([16, 6, 0.4]);
  color("#ece6d6") box(es_lb_conn);
}
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

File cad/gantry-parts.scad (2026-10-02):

// Printed parts for the XY gantry (OpenSCAD).
//
// Every part is modelled where it sits in the machine (see params.scad for
// the coordinate system), so cad/assembly.scad can place them without extra
// offsets. print_part() turns each one to its print orientation on the bed.
//
// Export one part:   openscad -D 'part="carriage"' -o carriage.stl gantry-parts.scad
// See them all:      leave part = "all" (a layout of every printed part)
// Or run cad/export.sh to write every STL and the renders.
//
// Parts: y-rod-holder (print 4), end-block-motor, end-block-idler,
// x-motor-mount, carriage, y-motor-mount, y-idler-mount, belt-clamp (print 4),
// x-endstop-mount, y-endstop-mount.
// PLA, 0.2 mm layers, 4 perimeters, 30% infill; no supports needed.
// idler_bore in params.scad picks the idlers (5 mm bore on M5 axles, or 3 mm
// on M3); it changes end-block-idler and y-idler-mount only.

include <params.scad>

part = "all";
show_names = false; // label each part in the "all" layout
$fn = 40;
eps = 0.01;

// ---------- Helpers ----------

// Circle with a 45-degree roof so a horizontal hole prints without support.
// roof = 1 points the roof to +Z, -1 to -Z (for parts printed upside down).
module tear2d(r, roof = 1) {
  scale([1, roof]) union() {
    circle(r);
    intersection() {
      rotate(45) square(r);
      translate([-r, 0]) square([2 * r, r * 1.15]);
    }
  }
}

module hole_x(d, len, roof = 1) {
  rotate([90, 0, 90]) linear_extrude(height = len, center = true) tear2d(d / 2, roof);
}

module hole_y(d, len, roof = 1) {
  rotate([90, 0, 0]) linear_extrude(height = len, center = true) tear2d(d / 2, roof);
}

module cyl_y(d, len) {
  rotate([90, 0, 0]) cylinder(d = d, h = len, center = true);
}

// Countersunk M3 hole along +Y, countersink on the y = 0 face.
module m3_flat_y(len) {
  rotate([-90, 0, 0]) {
    translate([0, 0, -1]) cylinder(d = m3_clear, h = len + 2);
    translate([0, 0, -eps]) cylinder(d1 = 6.8, d2 = m3_clear, h = 1.7);
  }
}

// Countersunk M3 hole along +X, countersink on the x = 0 face.
module m3_flat_x(len) {
  rotate([0, 90, 0]) {
    translate([0, 0, -1]) cylinder(d = m3_clear, h = len + 2);
    translate([0, 0, -eps]) cylinder(d1 = 6.8, d2 = m3_clear, h = 1.7);
  }
}

// Countersunk wood-screw hole through a plate of thickness t (top at z = t).
module wood_hole(t) {
  translate([0, 0, -1]) cylinder(d = wood_clear, h = t + 2);
  translate([0, 0, t - (wood_head_d - wood_clear) / 2]) cylinder(d1 = wood_clear, d2 = wood_head_d, h = (wood_head_d - wood_clear) / 2 + eps);
}

// Slot along Y for a pan-head wood screw, so the part can slide before tightening.
module wood_slot_y(len, t) {
  hull() for (s = [-1, 1]) translate([0, s * len / 2, -1]) cylinder(d = wood_clear, h = t + 2);
}

// ---------- Y rod holder (print 4) ----------
// Holds one end of a Y rod. Drawn for the front-left corner: rod along Y at
// x = 0, z = z_rod, block from y = 0 to holder_d, screw flange outboard (-X).
// Turn it 180 degrees about Z for the other side. Rod end flush with the
// outer face; an M3 x 6 grub screw in the top locks it.
module y_rod_holder() {
  difference() {
    union() {
      translate([-holder_w / 2, 0, 0]) cube([holder_w, holder_d, holder_h]);
      translate([-holder_w / 2 - holder_flange, 0, 0]) cube([holder_flange + eps, holder_d, flange_t]);
    }
    translate([0, holder_d / 2, z_rod]) hole_y(rod_hole, holder_d + 2, 1);
    translate([0, holder_d / 2, z_rod]) cylinder(d = m3_tap, h = holder_h);
    for (y = [holder_d / 4, 3 * holder_d / 4])
      translate([-holder_w / 2 - holder_flange / 2, y, 0]) wood_hole(flange_t);
  }
}

// ---------- End blocks ----------

// Two LM8UU pressed in from each end against a shoulder in the middle.
module y_bearing_bores(x) {
  inner = eb_lm_c - lm_len / 2;
  translate([x, 0, z_rod]) hole_y(lm_stop_d, 2 * eb_half + 2, -1);
  for (s = [-1, 1])
    translate([x, s * (inner + eb_half + 1) / 2, z_rod]) hole_y(lm_bore, eb_half + 1 - inner, -1);
}

// Left end block: rides the left Y rod, holds the left ends of both X rods,
// carries the X motor (through x_motor_mount) and the two Y belt clamps.
// Machine X, gantry Y. Printed upside down.
module end_block_motor() {
  sock_x0 = xL + house_hw;
  difference() {
    union() {
      translate([xL - house_hw, -eb_half, z_flat]) cube([2 * house_hw, 2 * eb_half, z_parts_top - z_flat]);
      translate([sock_x0 - eps, -eb_half, z_flat]) cube([eb_face_L - sock_x0 + eps, eb_half + eb_rear_L, z_parts_top - z_flat]);
    }
    y_bearing_bores(xL);
    for (s = [-1, 1]) {
      // X rod socket, 1 mm longer than needed so rod length tolerance is no problem
      translate([(rod_x0 - 1 + eb_face_L + 1) / 2, s * x_rod_dy, z_rod]) hole_x(rod_hole, eb_face_L + 2 - rod_x0, -1);
      // two M3 x 6 grub screws lock the X rod, one at each end of the socket
      for (x = [rod_x0 + grub_in, eb_face_L - grub_out]) translate([x, s * x_rod_dy, z_rod]) cylinder(d = m3_tap, h = 20);
      // Y belt clamps: one each side of the middle, two screws each
      for (t = [-1, 1]) translate([ybelt_x + t * clamp_screw, s * clamp_len / 2, z_flat - 1]) cylinder(d = m3_tap, h = clamp_pilot + 1);
    }
    // pocket for the X motor pulley and the upper belt run leaving it
    translate([x_pulley - pulley_flange_d / 2 - 1.5, xbelt_y - 9, z_flat - 1])
      cube([eb_face_L - x_pulley + pulley_flange_d / 2 + 2.5, eb_rear_L - xbelt_y + 10, 3.5]);
    // pilot holes for the two screws that hold the X motor mount
    for (x = mm_screw_x) translate([x, eb_rear_L + 1, mm_screw_z]) rotate([90, 0, 0]) cylinder(d = m3_tap, h = 13);
  }
}
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

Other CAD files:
cad/pieces.scad

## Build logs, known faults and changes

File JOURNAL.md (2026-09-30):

# Build journal

One entry per work session: what you did, what you learned, what's next,
and how long it took. Add photos or screenshots to `docs/img/` and link them.

| Date | Hours | Summary |
|---|---|---|
| | | |

**Total hours:** 0

---

## YYYY-MM-DD: title

**Time:** 0 h

**What I did**

-

**What I learned / what went wrong**

-

**Next**

-

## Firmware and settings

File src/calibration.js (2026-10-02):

/*
 * Works out where the board sits under the gantry, from the machine
 * positions the builder measured by jogging the magnet to the centers of a
 * few squares (always a1 and h8; h1 and a8 are optional extras).
 *
 * The result maps a cell (x, y) on the planner's grid (x from the left
 * storage column, y from rank 1, centers on whole numbers) to machine
 * millimetres:
 *
 *   machine = offset + (x + 0.5) * squareX * fileDir + (y + 0.5) * squareY * rankDir
 *
 * where offset is the machine position of the board's outer corner (left
 * storage column, rank-1 edge), fileDir is a unit vector turned rotationDeg
 * counterclockwise from machine +X, and rankDir is 90 + skewDeg degrees
 * further round. With no rotation or skew and squareX = squareY = the
 * nominal square, this is exactly what toGcode does with offsetX/offsetY.
 *
 * Two points can't tell a board that is slightly turned from one whose axes
 * are slightly stretched by different amounts: both move h8 the same way.
 * So with only a1 and h8 the fit assumes one square size for both axes and
 * solves for the rotation. Add h1 (and a8) to measure each axis separately
 * and how far the gantry is out of square; with four points it is a
 * least-squares fit and reports how well the points agree.
 */
import { cellAt, cellX, cellY, createBoard, parseCell } from './board.js';

const DEG = Math.PI / 180;

// Reads "X,Y" (millimetres) into { x, y }.
export function parsePoint(text) {
  const parts = String(text ?? '').split(',').map((part) => part.trim());
  const [x, y] = parts.map(Number);
  if (parts.length !== 2 || parts.some((part) => part === '') || !Number.isFinite(x) || !Number.isFinite(y)) {
    throw new Error(`"${text}" is not a position: give X,Y in millimetres, for example 60.5,-20`);
  }
  return { x, y };
}

// Grid cell { x, y } of a square name such as a1 or h8.
export function cellOf(name, storageColumns = 1) {
  const board = createBoard({ storageColumns });
  const cell = parseCell(board, name);
  return { x: cellX(board, cell), y: cellY(board, cell) };
}

// Cosine and sine of an angle in degrees, exact at multiples of 90 so an
// unrotated calibration gives exactly the same numbers as plain offsets.
function cosDeg(deg) {
  const turn = ((deg % 360) + 360) % 360;
  if (turn === 0) return 1;
  if (turn === 180) return -1;
  if (turn === 90 || turn === 270) return 0;
  return Math.cos(deg * DEG);
}
const sinDeg = (deg) => cosDeg(deg - 90);

// Machine position of a cell center; x and y may be fractions (routes run
// along half squares).
export function toMachine(calibration, x, y) {
  const { offsetX, offsetY, squareX, squareY, rotationDeg = 0, skewDeg = 0 } = calibration;
  const rankDeg = rotationDeg + 90 + skewDeg;
  const along = (x + 0.5) * squareX;
  const up = (y + 0.5) * squareY;
  return {
    x: offsetX + along * cosDeg(rotationDeg) + up * cosDeg(rankDeg),
    y: offsetY + along * sinDeg(rotationDeg) + up * sinDeg(rankDeg),
  };
}

// Throws unless the object has everything toMachine needs.
export function checkCalibration(calibration) {
  if (!calibration || typeof calibration !== 'object') throw new Error('The calibration must be an object (the contents of calibration.json)');
  for (const key of ['offsetX', 'offsetY', 'squareX', 'squareY']) {
    if (!Number.isFinite(calibration[key])) throw new Error(`The calibration has no valid ${key}`);
  }
  for (const key of ['rotationDeg', 'skewDeg']) {
    if (calibration[key] !== undefined && !Number.isFinite(calibration[key])) throw new Error(`The calibration's ${key} is not a number`);
  }
  if (calibration.squareX <= 0 || calibration.squareY <= 0) throw new Error('The calibration has a square size of zero or less');
  if (calibration.storageColumns !== undefined && !(Number.isInteger(calibration.storageColumns) && calibration.storageColumns >= 1)) {
    throw new Error('The calibration\'s storageColumns must be a positive whole number');
  }
  return calibration;
}

function wrapDegrees(deg) {
  return ((((deg + 180) % 360) + 360) % 360) - 180;
}

// Solves the 3x3 system m * v = b (Cramer's rule).
function solve3(m, b) {
  const det = (a) =>
    a[0][0] * (a[1][1] * a[2][2] - a[1][2] * a[2][1]) -
    a[0][1] * (a[1][0] * a[2][2] - a[1][2] * a[2][0]) +
    a[0][2] * (a[1][0] * a[2][1] - a[1][1] * a[2][0]);
  const d = det(m);
  if (Math.abs(d) < 1e-9) return null;
  return [0, 1, 2].map((col) => det(m.map((row, r) => row.map((v, c) => (c === col ? b[r] : v)))) / d);
}

// Two points: one square size for both axes, a rotation and an offset.
function fitTwo(cells, measured) {
  const run = { x: cells[1].x - cells[0].x, y: cells[1].y - cells[0].y };
  const seen = { x: measured[1].x - measured[0].x, y: measured[1].y - measured[0].y };
  const square = Math.hypot(seen.x, seen.y) / Math.hypot(run.x, run.y);
  const rotationDeg = wrapDegrees((Math.atan2(seen.y, seen.x) - Math.atan2(run.y, run.x)) / DEG);
  const unit = { offsetX: 0, offsetY: 0, squareX: square, squareY: square, rotationDeg, skewDeg: 0 };
  const first = toMachine(unit, cells[0].x, cells[0].y);
  return { ...unit, offsetX: measured[0].x - first.x, offsetY: measured[0].y - first.y };
}

// Three or more points: a least-squares affine fit, machine = J * (cell + 0.5) + offset.
function fitAffine(cells, measured) {
  const rows = cells.map((c) => [c.x + 0.5, c.y + 0.5, 1]);
  const normal = [0, 1, 2].map((i) => [0, 1, 2].map((j) => rows.reduce((sum, r) => sum + r[i] * r[j], 0)));
  const rhs = (axis) => [0, 1, 2].map((i) => rows.reduce((sum, r, k) => sum + r[i] * measured[k][axis], 0));
  const fx = solve3(normal, rhs('x'));
  const fy = solve3(normal, rhs('y'));
  if (!fx || !fy) throw new Error('The measured squares lie on one line; use corners such as a1, h8 and h1');
  const file = { x: fx[0], y: fy[0] }; // machine step for one file to the right
  const rank = { x: fx[1], y: fy[1] }; // machine step for one rank up
  if (file.x * rank.y - file.y * rank.x <= 0) {
    throw new Error('The board comes out mirrored: one machine axis runs the wrong way. Make +X run from file a to h and +Y from rank 1 to 8 (GRBL setting $3 reverses an axis), then measure again.');
  }
  const rotationDeg = Math.atan2(file.y, file.x) / DEG;
  const skewDeg = wrapDegrees(Math.atan2(rank.y, rank.x) / DEG - rotationDeg - 90);
  return {
    offsetX: fx[2],
    offsetY: fy[2],
    squareX: Math.hypot(file.x, file.y),
    squareY: Math.hypot(rank.x, rank.y),
    rotationDeg,
    skewDeg,
  };
}
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

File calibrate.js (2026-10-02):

/*
 * Fits the board to the gantry and writes calibration.json, which
 * toGcode and demo.js use to put every move on the real squares.
 *
 *   node calibrate.js --a1 X,Y --h8 X,Y [--h1 X,Y] [--a8 X,Y]
 *                     [--square 40] [--storage 1] [--out calibration.json] [--force]
 *
 * Measuring: home the machine, put a piece over the magnet, switch the
 * magnet on (M8) and jog until the piece sits in the middle of a1. Note the
 * X and Y your G-code sender shows, then do the same for h8. Use the work
 * position (WPos); it is the same as the machine position (MPos) unless a
 * work offset was set with G10 or G92.
 *
 * With a1 and h8 alone the fit assumes the same square size on both axes
 * and solves for the board's rotation. Measure h1 as well (and a8) to get
 * each axis's square size and how far the gantry is out of square.
 *
 * A fit far from the nominal board (src/calibration.js, CALIBRATION_LIMITS)
 * is refused: it almost always means a jog to the wrong square. --force
 * writes it anyway, for a board that has been checked and really is that
 * far out.
 */
import { writeFileSync } from 'node:fs';
import process from 'node:process';

import { cellAt, cellName, createBoard } from './src/board.js';
import { parsePoint, solveCalibration, toMachine } from './src/calibration.js';

const VALUE_FLAGS = ['--a1', '--h8', '--h1', '--a8', '--square', '--storage', '--out'];
const SWITCHES = ['--force'];
const USAGE = 'Usage: node calibrate.js --a1 X,Y --h8 X,Y [--h1 X,Y] [--a8 X,Y] [--square 40] [--storage 1] [--out calibration.json] [--force]';

function fail(message) {
  console.error(`${message}\n\n${USAGE}`);
  process.exit(2);
}

const args = process.argv.slice(2);
const given = {};
for (let i = 0; i < args.length; i++) {
  if (args[i] === '--help' || args[i] === '-h') {
    console.log(USAGE);
    console.log('\nJog the magnet to the center of each square after homing and give its X,Y in millimetres.');
    process.exit(0);
  }
  if (SWITCHES.includes(args[i])) {
    given[args[i]] = true;
    continue;
  }
  if (!VALUE_FLAGS.includes(args[i])) fail(`Unknown argument "${args[i]}".`);
  if (i + 1 >= args.length) fail(`${args[i]} needs a value.`);
  given[args[i]] = args[++i]; // values may start with '-' (negative positions)
}
if (!given['--a1'] || !given['--h8']) fail('Give at least --a1 and --h8.');

const squareMm = Number(given['--square'] ?? 40);
const storageColumns = Number(given['--storage'] ?? 1);
if (!(squareMm > 0)) fail('--square must be a size in millimetres, for example 40.');
if (!Number.isInteger(storageColumns) || storageColumns < 1) fail('--storage must be 1 or more.');
const out = given['--out'] ?? 'calibration.json';

const points = {};
for (const name of ['a1', 'h8', 'h1', 'a8']) {
  if (given[`--${name}`] === undefined) continue;
  try {
    points[name] = parsePoint(given[`--${name}`]);
  } catch (err) {
    fail(`--${name}: ${err.message}`);
  }
}

let result;
try {
  result = solveCalibration({ points, squareMm, storageColumns, force: Boolean(given['--force']) });
} catch (err) {
  console.error(`Can't calibrate: ${err.message}`);
  process.exit(1);
}
const { calibration: fit, warnings } = result;

const round = (value, digits) => Number(value.toFixed(digits));
const calibration = {
  about: 'Written by calibrate.js. Cell (x, y) is at offset + (x + 0.5) * squareX along the files + (y + 0.5) * squareY along the ranks; the files run rotationDeg counterclockwise from machine +X, the ranks 90 + skewDeg further.',
  squareMm,
  storageColumns,
  offsetX: round(fit.offsetX, 3),
  offsetY: round(fit.offsetY, 3),
  squareX: round(fit.squareX, 4),
  squareY: round(fit.squareY, 4),
  rotationDeg: round(fit.rotationDeg, 4),
  skewDeg: round(fit.skewDeg, 4),
  method: fit.method,
  measured: fit.measured,
  maxErrorMm: round(fit.maxErrorMm, 3),
  ...(fit.forced ? { forced: true } : {}),
};

const mm = (value, digits = 1) => `${value >= 0 ? ' ' : ''}${value.toFixed(digits)}`;
const percent = (size) => {
  const p = (size / squareMm - 1) * 100;
  return `${p >= 0 ? '+' : ''}${p.toFixed(2)}%`;
};
const twoPoints = Object.keys(points).length === 2;

console.log(`Board: ${squareMm} mm squares, ${storageColumns} storage column${storageColumns === 1 ? '' : 's'} on each side.`);
console.log(`Fit from ${calibration.method}.\n`);
console.log(`  Board corner (offsetX, offsetY)  ${calibration.offsetX.toFixed(3)}, ${calibration.offsetY.toFixed(3)} mm`);
if (twoPoints) {
  console.log(`  Square size                      ${calibration.squareX.toFixed(3)} mm on both axes (${percent(calibration.squareX)})`);
} else {
  console.log(`  Square size along the files      ${calibration.squareX.toFixed(3)} mm (${percent(calibration.squareX)})`);
  console.log(`  Square size along the ranks      ${calibration.squareY.toFixed(3)} mm (${percent(calibration.squareY)})`);
}
console.log(`  Rotation                         ${calibration.rotationDeg >= 0 ? '+' : ''}${calibration.rotationDeg.toFixed(3)} degrees (counterclockwise seen from above)`);
console.log(`  Out of square                    ${twoPoints ? 'not measured (add --h1)' : `${calibration.skewDeg >= 0 ? '+' : ''}${calibration.skewDeg.toFixed(3)} degrees`}`);
if (Object.keys(points).length > 3) console.log(`  Worst disagreement               ${calibration.maxErrorMm.toFixed(2)} mm between the measured squares and the fit`);

const board = createBoard({ storageColumns });
const corners = [
  [0, 7], [storageColumns, 7], [storageColumns + 7, 7], [board.width - 1, 7],
  [0, 0], [storageColumns, 0], [storageColumns + 7, 0], [board.width - 1, 0],
];
console.log('\nMachine positions of the corner cells:');
for (const [x, y] of corners) {
  const p = toMachine(calibration, x, y);
  console.log(`  ${cellName(board, cellAt(board, x, y)).padEnd(5)} X${mm(p.x).padStart(8)}  Y${mm(p.y).padStart(8)}`);
}

const all = [];
for (let x = 0; x < board.width; x++) for (let y = 0; y < board.height; y++) all.push(toMachine(calibration, x, y));
const span = (axis) => [Math.min(...all.map((p) => p[axis])), Math.max(...all.map((p) => p[axis]))];
const [minX, maxX] = span('x');
const [minY, maxY] = span('y');
console.log(`\nThe magnet must reach X ${minX.toFixed(1)} to ${maxX.toFixed(1)} and Y ${minY.toFixed(1)} to ${maxY.toFixed(1)} mm (every cell center).`);
console.log('With soft limits on ($20=1), that range must lie inside the travel set by $130 and $131.');

if (twoPoints) {
  console.log('\nTwo points cannot tell a slightly turned board from slightly different square sizes on each axis.');
  console.log('To measure both, also jog to h1 and add --h1 X,Y (and --a8 X,Y to check the fit).');
}
for (const warning of warnings) console.log(`\nWarning: ${warning}`);

writeFileSync(out, `${JSON.stringify(calibration, null, 2)}\n`);
console.log(`\nWrote ${out}. Use it with:`);
console.log(`  node demo.js reset --size 0.475 --calibration ${out} --gcode reset.gcode`);

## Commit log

2026-09-25 Add robotic chessboard arrangement planner and simulator
    A self-contained planner (chessboard/) that works out how a magnet under
    the board should drag pieces from any arrangement into any target:
    min-cost assignment of interchangeable pieces, ordering that breaks
    swap cycles with spare squares, A* routing that keeps a piece-width of
    clearance from every other piece, and clearing moves (aside and back)
    when full-size pieces are boxed in. Plans are replayed by an
    independent checker, can be exported as GRBL G-code, and can be
    watched in an animated top-down simulator. Includes a CLI demo and
    node:test suites covering sample jobs, random boards and Chess960
    setups. No changes to the Food Deser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
2026-09-25 Prepare chessboard/ to become the standalone chessboard-arranger repo
    Adds a hardware roadmap (ROADMAP.md) with milestones from a magnet test
    to online play, a repo-root README, MIT license, .gitignore, and a
    GitHub Actions workflow that runs the tests on Node 20 and 22. The
    folder is laid out so it can be split out as the root of its own repo.
    Claude-Session: https://claude.ai/code/session_015A824MCpLsmyTqmCE446C8
2026-09-30 Add v1 hardware design, parts list, CAD and build journal
    - docs/DESIGN.md: compact 40 mm-square board, gantry, wiring, GRBL
    settings, test plan and open questions
    - docs/BOM.md: about $99 of parts for the first build
    - cad/: 1:1 printable board sheet and dimensioned layout (generated by
    make-board.js) and parametric OpenSCAD pieces with a washer pocket
    - README rewritten as the project front page; roadmap updated to the
    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
    [pieces.scad]
2026-10-01 Add handoff for the remaining design work
    docs/HANDOFF.md explains what is left before the funding deadline and the
    prompt to resume it from a new session. The workflow that runs the five
    remaining tracks (parts sourcing, gantry CAD, schematic, calculations,
    GRBL sender) is saved in .claude/workflows/. docs/bom-draft.md keeps the
    first, unverified parts research so it isn't redone.
    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
2026-10-02 Add gantry CAD, wiring, calculations, GRBL sender and checked parts list
    Results of the design-push workflow (five tracks, each built, reviewed
    independently and fixed), checked and integrated:
    - cad/: params, 16 printed gantry parts with STLs, the full assembly with
    reach, clearance, belt, endstop and interference checks, export.sh and
    four renders in docs/img/. All 11 checks pass.
    - cad/make-wiring.js draws the wiring schematic (docs/img/wiring.svg/png).
    - docs/CALCULATIONS.md, with every figure printed by scripts/calculations.js.
    - send.js, calibrate.js, src/grbl.js, src/send-job.js, src/calibration.js;
    toGcode accepts a calibration. 70 tests pass; serialport is optional.
    - docs/BO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
    [assembly.scad, belt-clamp.stl, carriage.stl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]
2026-10-02 Fit the funded parts list under $100, with add-backs for build time
    The full-spec list came to $116.38 with tax. Four parts are cut or
    downgraded in the funded list, which now comes to $98.36:
    - The belt kit's two 5 mm-bore idlers replace a separate pack of 3 mm
    idlers. The CAD's idler bore is now a setting (idler_bore 5, the
    default, on M5 axles; or 3 on M3 axles), with checks for both, an
    IDLER_BORE switch in export.sh and a redesigned Y idler mount. Only the
    idler end block and Y idler mount STLs change.
    - No felt pads. CALCULATIONS.md now leads with the no-felt case (3.4 mm
    gap, king tips at 13600 mm/s^2, 11500 if the washer sits flush).
    - A 12 V 3 A adapter. CALCULATIONS.md a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
    [assembly.scad, end-block-idler.stl, gantry-parts.scad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]
